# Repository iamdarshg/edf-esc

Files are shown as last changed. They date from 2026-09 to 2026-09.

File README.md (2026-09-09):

# EDF-ESC

Open hardware and firmware for a compact 98 mm × 58 mm, four-layer board with
two independent 6S sensorless BLDC/EDF controller channels.

> **Engineering prototype — do not fabricate or connect a battery.** The CAD
> currently contains documented placement placeholders, open nets, and DRC
> violations. It is not a validated 150 A design. See
> [`docs/cad-status.md`](docs/cad-status.md) for the exact blockers.

## Design targets

- two electrically independent power paths; no shared 300 A PCB segment;
- 18 × SFS06R025GF per channel, three devices per switch;
- DRV8300D gate driver and PY32F030K28U6TR controller per channel;
- high-side copper-shunt/INA190A3 current sensing with four-wire calibration;
- sensorless six-step control with PWM throttle and shared SPI/separate CS;
- shared 12 V gate supply, 5 V/8 A characterization-target BEC, and 3.3 V logic;
- JLCPCB/LCSC-first sourcing with Mouser alternatives and top-side assembly;
- top-side CNC copper reinforcement for every high-current path.

## What works today

The calculation engine, BOM/pin-mux contracts, host protocol, commutation table,
startup/control state machine, zero-cross detector, protection model, and both
channel configuration contracts are covered by native tests. KiCad 7.0.11
parses the generated review CAD and exports plots.

```sh
python3 -m venv .venv
.venv/bin/pip install -e '.[test]'
make test
.venv/bin/python -m edf_esc.cad
```

## Repository map

- `hardware/` — deterministic KiCad review project and design-rule contracts
- `firmware/` — tested portable control core and PY32 pin/configuration contract
- `host/` — SPI framing reference
- `bom/` — primary and alternate sourcing tables
- `calculations/` — gate, MOSFET, shunt, copper, and BEC estimates
- `docs/` — architecture, protocol, safety status, and source ledger

The progression to powered testing is intentionally gated: inspection, gate-only
testing, current-limited low-voltage switching, 3S motor testing, restricted 6S,
then thermal/electrical characterization. A numerical current ceiling is not a
continuous-current rating.

## License

MIT. See [`LICENSE`](LICENSE). Component datasheets and vendor SDK files are not
redistributed unless their licenses permit it.

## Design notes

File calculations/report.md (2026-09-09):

# EDF-ESC preliminary electrical calculations

> Design estimates only. Values that depend on waveforms, copper plating, airflow, component temperature, or undocumented vendor behavior require measurement before power testing.

## Gate drive

Three 81 nC gates place 243 nC on each DRV8300 output. The 0.75 A source and 1.5 A sink ratings give optimistic lower bounds of 324 ns turn-on and 162 ns turn-off. Actual Miller-plateau edges will differ. A 4.7 ohm resistor per MOSFET is the initial damping value; all 36 footprints permit tuning.

At 12 V, gate-charge power per ESC is `18 * 81 nC * 12 V * f`:

| PWM | One ESC | Both ESCs |
|---:|---:|---:|
| 12 kHz | 0.210 W | 0.420 W |
| 16 kHz | 0.280 W | 0.560 W |
| 20 kHz | 0.350 W | 0.700 W |
| 24 kHz | 0.420 W | 0.840 W |

Using the optimistic 486 ns combined edge time, 25.2 V, and 150 A, one hard-switching group dissipates approximately 11.0, 14.7, 18.4, and 22.0 W at 12, 16, 20, and 24 kHz. Modulation can expose more than one group to hard switching, so layout thermal work uses a 1x-2x bracket until double-pulse measurements replace this estimate. This supports the 16 kHz default and argues against 24 kHz during initial tests.

## MOSFET conduction

Assuming 2.0 milliohm per FET at 25 C and a provisional 1.7 hot multiplier, one three-FET group is 1.13 milliohm. A six-step current path contains one high and one low group, or about 2.27 milliohm before copper and sharing error.

| Phase current | Two-group conduction |
|---:|---:|
| 100 A | 22.7 W |
| 120 A | 32.6 W |
| 150 A | 51.0 W |

These are bridge-level path estimates, not per-FET dissipation. Unequal sharing and temperature feedback are validation risks.

## Copper shunt

One 70 um outer-copper strip 11.6 mm long by 28 mm wide calculates to 99.4 microohm at 20 C. At 150 A it produces 14.9 mV and 2.24 W; INA190A3 gain of 100 produces about 1.49 V. At 100 C the copper model rises by about 31%, so four-wire calibration and temperature compensation are mandatory. Finished plating and soldered reinforcement must stop exactly at the Kelvin boundaries.

## 5 V BEC

For 25.2 V to 5.0 V at 180 kHz with 47 uH, ideal duty is 19.84% and calculated inductor ripple is 0.474 A peak-to-peak. At an 8 A target the ideal inductor peak is 8.24 A, so the selected inductor must retain useful inductance comfortably beyond that current. With a provisional 0.55 V diode drop, diode loss alone is about 3.53 W at 8 A. The BEC therefore requires airflow and 2/4/6/8 A thermal characterization; 8 A is not a guaranteed continuous rating.

## BEMF divider and clamp

The starting divider uses two series 47 kOhm upper resistors and 12 kOhm lower,
followed by 1 kOhm into the ADC clamp. At 25.2 V the open divider output is 2.85
V. A deliberately conservative 60 V phase transient would produce 6.79 V if
unclamped. With a 3.6 V clamp model, the upper/lower Thevenin resistance plus the
1 kOhm series resistor limits current to about 0.274 mA. This proves that a naked
divider is unacceptable; it does not close the gate until the exact PY32
injected-current limit, BAT54 leakage, RC settling, and captured phase overshoot
are verified.

## Mandatory measurements

Measure gate plateau/rise/fall, deadtime, phase-node overshoot, bootstrap droop, DC-link ripple, current-sharing proxy temperatures, four-wire shunt resistance, current-amplifier offset/gain, BEMF settling after blanking, and BEC component temperatures. Replace assumptions in `inputs.yaml` only with traceable measurements in `validation/ledger.csv`.

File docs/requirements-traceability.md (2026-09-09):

# Requirements traceability

This table distinguishes implemented evidence from remaining work. “Pass” means
an automated structural or software check passes; it does not imply physical
validation.

| Requirement | Evidence | Status |
|---|---|---|
| One board, two independent ESC paths | `hardware/edf-esc.kicad_pcb`, CAD tests | structural pass |
| ≤100 × 60 mm; four layers; top-side only | 98 × 58 generator contract and tests | pass |
| 36 exact MOSFETs; individual gate resistors | BOM, generated PCB, CAD tests | pass |
| DRV8300D, MCU, INA190 per channel | BOM and review CAD | placement only |
| Proven simultaneous MCU pin mux | `hardware/pinmux.csv`, contract tests | pass |
| BEMF sensing and sensorless control | named CAD nets, `sensorless.c`, tests | firmware pass; analog CAD open |
| PWM throttle + shared SPI/separate CS | pin map, `host/protocol.py`, tests | protocol pass; platform open |
| Command-loss and emergency shutdown | `control.c`, native tests | pass |
| Current, thermal, UV/OV, stall protection | `control.c`, native tests | sampled model pass; hardware open |
| 12 V, 5 V BEC, 3.3 V rails | calculations and BOM | detailed CAD open |
| Loss, shunt, gate, and buck calculations | `calculations/report.md`, calculation tests | pass as estimates |
| Complete connected schematic and exact footprints | `docs/cad-status.md` | blocked |
| Fully routed, zero-error DRC PCB | KiCad DRC report | blocked |
| Target PY32 ELF/HEX/BIN | `docs/firmware.md` | blocked |
| JLCPCB BOM/CPL/Gerbers/drill package | release gate | blocked until CAD passes |
| CNC copper reinforcement drawings | `hardware/mechanical/` | preliminary profiles; final cutouts blocked by routing |
| Physical staged validation at 3S/6S/full load | validation ledger | pending hardware |

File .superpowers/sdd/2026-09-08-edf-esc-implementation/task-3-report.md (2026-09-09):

# Task 3 final report

## Files changed

`edf_esc/cad.py`, `hardware/edf-esc.kicad_sch`, `hardware/lib/edf-esc.kicad_sym`, and structural CAD tests.

## Verification

- `PYTHONPATH=/workspace/scratch/10bf20402490/edf-esc-test-venv-broken/lib/python3.12/site-packages python3 -m pytest tests -q`: 28 passed.
- `make test-c`: all control, sensorless, and platform contract tests passed.
- `python3 -m py_compile edf_esc/cad.py`: passed.
- Generated twice and compared with `cmp`: passed.
- `git diff --check`: passed.
- Exact attachment count: 508 zero-length wires, coincident with serialized pin endpoints.

## KiCad limitation

KiCad CLI bus-errors in this environment; no parse/export success is claimed and ERC was not run.

## Final commit

`112a2f482d7b757c832b0c4c4258686488903111`

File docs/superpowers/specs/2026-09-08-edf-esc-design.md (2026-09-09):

# EDF-ESC Dual 6S Sensorless Controller Design

## Status and safety boundary

EDF-ESC is a public, open engineering prototype for two independently controlled 6S sensorless BLDC/EDF motors. It is not a certified product and is not rated for 150 A continuous operation. Initial firmware restricts current and duty cycle; 150 A is an experimental hard ceiling unlocked only after staged electrical and thermal characterization. Fabrication files remain marked `UNVALIDATED` until the validation ledger records oscilloscope, current-calibration, thermal, and powered-motor results.

## Physical architecture

The board is a 98 mm x 58 mm, four-layer, 1.6 mm FR4 PCB. All components, connectors, test pads, and reinforcement metal are on the top side. ESC A occupies the left power zone and ESC B the right power zone. A central low-current zone contains the shared 12 V gate supply, 5 V BEC, 3.3 V logic rail, and control connector. Each channel has its own battery pads, calibrated shunt geometry, local DC-link capacitors, bridge, phase pads, gate driver, MCU, analog sensing, and return path. The battery is star-split externally; no PCB segment carries both channels' motor current.

Each of the six half-bridge switches per channel contains three SFS06R025GF MOSFETs in parallel. Every MOSFET has its own tunable gate resistor fed by a matched star fan-out from one DRV8300D output. Gate-source pulldowns are per switching group. Optional RC snubbers are fitted across all phase-switching nodes.

## Power path and reinforcement

High-current paths use broad outer-layer polygons, deliberate inner-layer reinforcement, dense via arrays, and short local loops. Top-side solder-mask openings accept CNC-cut 1-2 mm copper bars or braid on BAT+, BAT-, and phase paths. The repository includes dimensioned DXF reinforcement profiles. Eight-AWG cable lands are top-side slotted pads with strain-relief holes. The copper bars are part of the prototype's current path and are not optional at high current.

The layer intent is:

- L1: components, gate fan-outs, local DC-link loops, exposed high-current copper, analog islands.
- L2: channel-local power returns and quiet signal references; split so neither motor return crosses the other channel.
- L3: channel-local battery/phase reinforcement and auxiliary-power distribution.
- L4: additional return/power reinforcement and low-risk signal routing.

No switching node is allowed beneath an MCU, current amplifier, SPI trace, PWM input, or Kelvin pair.

## Sensing and protection

Each BAT+ branch includes a nominal 0.10 milliohm defined copper shunt with true Kelvin boundaries, four-wire calibration pads, and a nearby 10 kohm NTC. An INA190A3 produces the current ADC signal. The PCB also carries an unpopulated metal-shunt fallback footprint. Firmware converts offset-corrected ADC counts through a stored calibration coefficient and optionally compensates copper temperature using 0.0039/K before calibrated corrections.

Each phase has a protected high-impedance BEMF divider, RC filter, ADC series resistor, and clamp chosen so the MCU pin remains inside its injected-current and voltage limits during 6S switching transients. Each channel separately measures VBUS, current, shunt temperature, and power-stage temperature. Floating-phase zero crossing is compared in software with measured VBUS/2.

The hardware break path uses the PY32 comparator-to-TIM1-BREAK route only if the reference manual proves simultaneous pin and internal-route availability. Otherwise, a fast external comparator drives TIM1 BREAK. This independent path is in addition to sampled software current limiting. DRV8300 faults, watchdog, UVLO/OVLO, startup timeout, stall, lost commutation, desynchronization, throttle loss, SPI timeout, and overtemperature all force a coast-safe state.

## Supplies

One XL1509-derived 12 V rail supplies both DRV8300D devices through separate local filters and at least 10 uF local ceramic capacitance per driver. Worst-case average gate-drive demand is calculated from 36 MOSFETs, gate charge, and PWM frequency.

One XL4016E1 non-synchronous buck provides a target 5.0 V/8 A BEC through top-side heavy-wire pads. The design follows the manufacturer's reference topology and documents inductor ripple, saturation current, diode stress, capacitor ripple, and estimated losses. Eight amperes is a characterization target, not a guaranteed continuous rating. An XC6206-class LDO generates 3.3 V for both MCUs and analog circuitry.

## Control and firmware

Each PY32F030K28U6TR uses TIM1 complementary PWM with hardware deadtime. A checked pin-mux table must demonstrate simultaneous six PWM outputs, three BEMF ADC inputs, current ADC, VBUS ADC, at least one NTC ADC, PWM throttle input, SPI slave with independent CS and tri-stated MISO, fault/break, and SWD. If the exact QFN-32 package cannot satisfy this concurrently after all documented remaps, the BOM may move to the cheapest stocked compatible MCU, with the rejected mapping and cost delta recorded.

Both MCUs run the same bare-metal C source with a channel configuration constant. The nonblocking state machine is `DISARMED -> ALIGN -> OPEN_LOOP_RAMP -> CLOSED_LOOP -> FAULT`. Closed-loop six-step commutation blanks switching noise, detects the correct floating-phase crossing around VBUS/2, schedules nominal 30-electrical-degree commutation delay, and applies configurable advance. Default PWM is 16 kHz; supported evaluation settings are 12, 16, 20, and 24 kHz. The default motor is four-pole, while pole count is configurable.

PWM throttle accepts a configurable range centered on 1000-2000 us at 50-400 Hz and becomes invalid after 100 ms. The shared SPI bus uses separate chip selects. Frames contain sync, command, payload length, payload, and CRC-8. Commands cover throttle, arm/disarm, emergency stop, PWM frequency, current limits, ramp rate, optional direction configuration, telemetry, faults, and firmware version. An inactive slave releases MISO.

Default protection starts conservative: a 100 A software target, soft limiting from 120 A, aggressive limiting at 130 A, and an inaccessible 150 A ceiling until characterization data enables it. Temperature warning/derating starts at 80-90 C and shutdown at 100-110 C, all configurable and explicitly described as PCB/NTC rather than junction temperatures.

## Repository deliverables

- `hardware/edf-esc.kicad_sch`, `hardware/edf-esc.kicad_pcb`, project settings, custom symbols, and custom footprints.
- `hardware/mechanical/` with board drawing, STEP export when the CLI supports it, and CNC reinforcement DXF files.
- `firmware/common/`, `firmware/platform/py32f030/`, and channel configurations with reproducible builds.
- `host/` reference SPI encoder/decoder and calibration utilities.
- `tests/` host-executable tests for commutation tables, state transitions, CRC/framing, protection limits, calculations, BOM integrity, pin-mux completeness, and manufacturing-file presence.
- `bom/` with JLCPCB/LCSC-first and Mouser-secondary sourcing, prices captured with dates, alternatives, and selection reasons.
- `calculations/` with machine-readable inputs and generated reports for gates, switching/conduction loss, shunt geometry, BEC, DC-link, and copper loss.
- `manufacturing/` with Gerbers, drill files, BOM/CPL, fabrication notes, assembly drawings, and SHA-256 manifests.

## Verification gates

Automated gates are KiCad ERC with reviewed exclusions, KiCad DRC, board dimension and top-side-only checks, BOM-reference consistency, firmware compilation, host tests, formatting/static analysis, Gerber/drill generation, and clean regeneration from scripts. Passing automation means the files are internally consistent; it does not validate high-current performance.

Physical gates progress through: unpowered inspection; gate-only testing; current-limited low-voltage switching; 3S low-power motor operation; 6S restricted-current operation; then full characterization. Each stage records supply limits, load, waveforms, deadtime, ringing, temperatures, current-calibration error, observed faults, operator, date, and artifact hashes. Full-power use requires validated bus transient margin, equal gate behavior among parallel FETs, stable BEMF handoff, shunt calibration, acceptable MOSFET/PCB/BEC temperatures, and a documented safe operating envelope.

## Engineering assumptions

JLCPCB is the fabrication and primary top-side PCBA target. LCSC is the first sourcing choice and Mouser is the verified secondary source. The board uses separate BAT_A and BAT_B leads from an external star point, 8-AWG cable at full-power experiments, forced airflow from the EDF installation, and soldered top copper reinforcement for any test above the low-current bring-up envelope. Exact component ratings, footprints, availability, and pin functions come from archived manufacturer datasheets, never distributor headlines alone.

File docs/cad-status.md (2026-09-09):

# CAD status

The checked-in CAD is a deterministic **placement and power-topology review
prototype**, not a fabrication release. It is deliberately marked
`UNVALIDATED` on the silkscreen and schematic.

## Verified automatically

- KiCad 7.0.11 parses the board and schematic and exports Gerber/PDF files.
- Outline is 98 mm x 58 mm with four copper layers.
- Every footprint is on the front side.
- There are exactly 36 `SFS06R025GF` positions and 36 individual 4.7 ohm gate
  resistors.
- Channel A and B have independent battery, phase, Kelvin, BEMF, and break nets.
- Source files regenerate byte-for-byte from `python -m edf_esc.cad`.

## Open fabrication blockers

- The centre section now uses package-structured QFN-24, QFN-32-EP, TSOT-23-8,
  SOIC-8, TO-220-5, and SOT-23 pads, but their courtyard, paste, thermal-via,
  assembly, and manufacturer land-pattern dimensions still require final review.
- The schematic is a functional-block review sheet, not the final connected
  electrical schematic.
- The latest local KiCad DRC after assigning the control-device pins reports 895
  violations and 157 unconnected pads. This is expected to rise as real nets
  replace stand-ins; it is not a regression to hide by suppressing checks.
- Copper-zone geometry, gate fan-out, creepage, silkscreen, thermal vias, and
  busbar interfaces need final routing review.
- ERC/DRC must reach reviewed zero-error status before manufacturing files are
  allowed into a release archive.

Do not order this revision. Generated plots are parser smoke-test artifacts only.

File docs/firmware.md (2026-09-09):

# Firmware architecture and status

Both ESCs use the same C11 control sources. `firmware/esc_a/config.h` and
`firmware/esc_b/config.h` change only channel identity; both retain 16 kHz PWM,
a four-pole motor default, and the compile-time high-power lock.

## Implemented and host-tested

- coast-safe six-step output table;
- `DISARMED -> ALIGN -> OPEN_LOOP_RAMP -> CLOSED_LOOP -> FAULT` state machine;
- switching blanking and hysteretic floating-phase zero-cross detection;
- 30-electrical-degree commutation timing with configurable advance;
- current and temperature duty derating;
- latched hard overcurrent, overtemperature, UV, OV, stall, control-timeout,
  and emergency-stop faults;
- CRC-8 command framing and the shared-SPI MISO release rule;
- compile-time validation of the exact QFN-32 TIM1, ADC, throttle, SPI, break,
  and SWD pin allocation for both channel variants.

Run `make test` for the native test suite. The safety core is deliberately free
of PY32 register access so it can be tested with warnings-as-errors and
sanitizers on a workstation.

## Embedded-build blocker

The repository does not yet contain a vendor startup file, CMSIS device header,
linker script, or completed register-level platform implementation. Therefore it
does not yet emit honest `.elf`, `.hex`, or `.bin` images. Those pieces must be
added from a redistributable Puya SDK revision, then the resulting 64 KiB flash / 8
KiB SRAM map must be checked before the firmware is flashed. The pin contract is
ready, but a host build must not be mislabeled as target firmware.

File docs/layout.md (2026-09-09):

# Layout intent and routing constraints

The 98 × 58 mm outline is divided into a left ESC A power cell, a narrow central
control/auxiliary corridor, and a right ESC B power cell. Battery leads star-split
outside the PCB. `BAT_A±` and `BAT_B±` never merge into a board-level motor-current
bus; only low-current auxiliary returns meet at the defined logic star.

Each phase row places three high-side and three low-side PDFN 5×6 devices around a
short local phase polygon. A driver output fans to three equal-length branches,
each terminating in its own 4.7 Ω resistor at the MOSFET gate. Source sense returns
to the driver separately from load copper. Bootstrap capacitor loops must fit
inside the driver/half-bridge cell, with no via in the high-current commutation
loop unless the via array is explicitly modeled.

The current board is not yet routed to this standard. Final routing must enforce:

- 0.5 mm minimum 6S power clearance, increased wherever routing space allows;
- no phase copper below MCU, INA190, SPI, throttle, SWD, or Kelvin routes;
- paired Kelvin traces from the exact copper-shunt boundaries, guarded by quiet
  reference copper and never sharing a current-carrying via;
- high-frequency ceramics directly across each half-bridge local bus loop;
- driver GVDD and bootstrap capacitors adjacent to their pins;
- front-only test points for every gate, phase, bus, current, BEMF, break, and rail;
- at least 1 mm copper-to-edge clearance and isolated M3 keepouts;
- mask openings and mechanical datum holes that register the CNC copper profiles;
- no thermal relief on cable lands or reinforcement interfaces;
- a local via array at each power-pad transition, with drill/aspect ratio accepted
  by the selected JLCPCB four-layer process.

KiCad net classes in `hardware/net-classes.json` are the minimum starting values,
not proof of current capacity. Final current capability depends on the soldered
C110 bars, joints, cable termination, airflow, switching losses, and measured
temperature rise.

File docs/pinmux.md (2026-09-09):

# PY32F030K28U6TR pin-mux decision

The selected QFN-32 K2 device can expose the three complementary TIM1 pairs while retaining six ADC inputs, SPI2, throttle capture, hardware break, reset, and SWD. `hardware/pinmux.csv` is the machine-checked allocation. It is based on PY32F030 Datasheet Rev1.3, QFN32 K2 pin definition table 4-2 and alternate-function tables 4-4/4-5.

TIM1 uses PA8/PA7 for CH1/CH1N, PA9/PB0 for CH2/CH2N, and PA10/PB1 for CH3/CH3N. Analog inputs PA0-PA5 cover current, VBUS, three BEMF phases, and one power-stage NTC. SPI2 avoids those pins by using PF0 SCK, PB7 MOSI, PF1 MISO, and PB8 as software NSS. PB4 captures throttle with TIM3_CH1. PA6 is TIM1_BKIN. PA13/PA14 retain SWD and PF2 retains reset.

## Corrected gate-driver fault requirement

DRV8300DRGER has no `nFAULT` output pin. Its UVLO and cross-conduction features act internally but cannot satisfy the prompt's requested gate-driver-fault input. The design therefore monitors the 12 V gate rail with an external supervisor/comparator on PB5 and routes the fast overcurrent comparator directly to PA6/TIM1_BKIN. Firmware reports `GATE_SUPPLY_FAULT`; it must not mislabel that signal as internal DRV8300 diagnostics.

## ADC-resource consequence

All six conveniently routed ADC channels are used. The base build provides one NTC ADC per channel, satisfying the mandatory requirement. A second NTC footprint can be populated through an analog multiplexer option but is not part of the minimum build because it would add cost and sampling complexity.

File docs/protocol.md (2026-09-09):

# SPI control protocol

Each MCU is an SPI mode-0 slave on the shared clock/MOSI/MISO bus and has an
independent active-low chip select. The inactive slave configures MISO as an
input (high impedance); it must never drive the shared line while its CS is
high.

Frames are `A5 command length payload crc8`. Length is one byte and covers only
the payload. CRC is CRC-8/ATM (polynomial `0x07`, initial value zero) over every
preceding byte including sync. Multi-byte integers are little-endian.

| Value | Command | Request payload |
|---:|---|---|
| `0x01` | ARM | none |
| `0x02` | DISARM | none |
| `0x03` | EMERGENCY_STOP | none; fault latches |
| `0x10` | SET_THROTTLE | duty, `uint16` |
| `0x11` | SET_PWM_FREQUENCY | hertz, `uint32` |
| `0x12` | SET_CURRENT_LIMIT | milliamps, `uint32` |
| `0x13` | SET_RAMP_RATE | electrical steps/s², `uint32` |
| `0x14` | SET_DIRECTION | `0` forward, `1` reverse |
| `0x20` | READ_TELEMETRY | none |
| `0x21` | READ_FAULTS | none |
| `0x22` | READ_VERSION | none |

Any malformed length, unknown command, or CRC mismatch is discarded without
changing outputs. The valid-control watchdog is refreshed only after a complete,
accepted control frame. It forces a latched coast-safe fault after 100 ms.

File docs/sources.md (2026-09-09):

# Controlled engineering sources

Only manufacturer documents can close an electrical or pin-mux gate. Distributor pages support stock, price, and ordering identity but not design limits.

| Component | Controlled source | Facts used | Status |
|---|---|---|---|
| TI DRV8300 | https://www.ti.com/lit/ds/symlink/drv8300.pdf, Rev. D (March 2022), SHA-256 `bb467652a531335d23ea67644db1db26ce53f149e3f889f8158a1c3ddac3e4db` | 5-20 V GVDD, 750 mA source, 1.5 A sink, QFN variable deadtime, integrated bootstrap diode on D variant, pinout/layout | verified from manufacturer PDF |
| TI INA190 | https://www.ti.com/lit/ds/symlink/ina190.pdf, Rev. D, SHA-256 `6ed9c2cc41d6c5ba4f36ce33d9d829b2f0c51e376583e94e2c63be4d950b39af` | common-mode range, gain option, supply/ADC interface, layout | verified from manufacturer PDF |
| PUYA PY32F030 | LCSC manufacturer PDF mirror, Datasheet Rev1.3, SHA-256 `38262b8a2c8320567f7f80594d4e9558cd0721edacbe360e37839284c0d04a4f` | exact QFN-32 K2 pins, alternate functions and ADC channels | pin map verified; comparator internal routing still requires reference-manual evidence |
| Oriental Semiconductor SFS06R025GF | Manufacturer PDF V1.0, SHA-256 `6a947af2537023168338109af4bddd3e03c0364027fd04a3ce05bfe177fd5f03` | 60 V, 2.5 mOhm maximum at 10 V, 81 nC Qg, 16 nC Qgd, PDFN 5x6 pinout | verified from manufacturer PDF; thermal assumptions remain a physical validation gate |
| XLSEMI XL4016E1 | Manufacturer datasheet, 8 A/180 kHz/40 V family | reference circuit, feedback, inductor, diode, capacitors, thermal limits | secondary mirror located; manufacturer PDF must be archived |
| XLSEMI/UMW XL1509 | Manufacturer datasheet for exact ordered variant | 12 V buck reference circuit and magnetics | validation gate before schematic release |
| XC6206P332MR | Torex manufacturer datasheet | pinout, 3.3 V regulation, capacitor stability, current/thermal limits | validation gate before schematic release |

## Distributor capture

LCSC product pages were captured on 2026-09-09 for ordering identity, prototype
price, and stock only: C49005839 (259), C3655801 (11,428), C3018718 (18,245),
C1852076 (8,100), C55881 (26,710), and C2681227 (13,060). Distributor values do
not override the electrical limits above. Prices in `bom/edf-esc.csv` use the
lowest applicable quantity tier for one board, including LCSC minimum-order
tiers where relevant.

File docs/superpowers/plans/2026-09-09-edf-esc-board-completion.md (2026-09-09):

# EDF-ESC Board Completion Implementation Plan

> **For agentic workers:** REQUIRED SUB-SKILL: Use superpowers:subagent-driven-development (recommended) or superpowers:executing-plans to implement this plan task-by-task. Steps use checkbox (`- [ ]`) syntax for tracking.

**Goal:** Turn the existing EDF-ESC engineering prototype into a complete, pin-accurate, ERC/DRC-clean dual-6S KiCad design with target firmware and reproducible JLCPCB manufacturing outputs, while keeping the public repository honest about unvalidated high-current performance.

**Architecture:** Keep the 98 mm × 58 mm mirrored board: ESC A on the left, ESC B on the right, and low-current auxiliary/control circuitry in the centre. Make a connected KiCad schematic the sole netlist authority, then update the PCB from it; use channel-local high-current loops and top-side CNC copper reinforcement so no PCB segment carries combined motor current. Continue the deterministic Python generators, fail-closed release gate, and shared host-tested firmware core with channel-specific PY32 configuration.

**Tech Stack:** KiCad 9 source format with KiCad 7.0.11 compatibility checks, Python 3.12/pytest, C11, GNU Arm Embedded, JLCPCB/LCSC assembly conventions, Mouser secondary sourcing, Git/GitHub Actions.

**Spec:** `docs/superpowers/specs/2026-09-08-edf-esc-design.md`

## Global Constraints

- Board outline remains exactly 98 mm × 58 mm and never exceeds 100 mm × 60 mm.
- Four copper layers, 1.6 mm FR4; 2 oz all layers where economical, otherwise 2 oz outer layers and the thickest economical inner copper with the deviation documented.
- All component bodies, connectors, cable lands, test pads, and reinforcement remain top-side only.
- BAT_A and BAT_B remain independent from their external star split through their local bridges; no combined-current PCB net or segment is allowed.
- Exactly 36 SFS06R025GF MOSFETs: three per switch, 18 per ESC, with one tunable gate resistor per MOSFET and no daisy-chained gates.
- One DRV8300DRGER and one PY32F030K28U6TR per ESC; do not invent a DRV8300 `nFAULT` pin.
- Default PWM remains 16 kHz; firmware retains 12/16/20/24 kHz evaluation options.
- Default limits remain 100 A target, 120 A soft limit, 130 A aggressive limit, and a locked 150 A experimental ceiling.
- JLCPCB/LCSC is the primary build path; Mouser is the verified secondary source.
- Automation proves internal consistency only. The project remains `UNVALIDATED` and non-fabrication-ready until ERC, DRC, sourcing, and staged physical gates are complete.

---

### Task 1: Publish and continuously synchronize the engineering baseline

**Files:**
- Modify: Git remote `iamdarshg/EDF-ESC`, branch `main`
- Verify: `.github/workflows/ci.yml`, `README.md`, `docs/cad-status.md`

**Interfaces:**
- Consumes: local audited commits and GitHub public repository created by the user.
- Produces: a public source-of-truth branch whose visible head is recorded after every reviewed milestone.

- [ ] Create one Git tree containing every `git ls-files` path, preserving mode `100644`/`100755`.
- [ ] Commit that tree on remote `main` with the existing seed commit as parent.
- [ ] Fetch the remote head and compare the uploaded file set and representative SHA/content for `hardware/edf-esc.kicad_pcb`, `edf_esc/cad.py`, and `scripts/check_release.py`.
- [ ] Keep `README.md` and `docs/cad-status.md` explicit that the current CAD is not safe to fabricate.
- [ ] After every later task passes review, publish its commit and re-verify the remote head.

Verification:

```sh
git ls-files | sort
git status --short
git diff --check
```

Commit message: `chore: publish EDF-ESC engineering baseline`

### Task 2: Freeze pin-accurate symbols and manufacturer land patterns

**Files:**
- Modify: `edf_esc/cad.py`
- Modify: `hardware/lib/edf-esc.kicad_sym`
- Modify: `hardware/lib/edf-esc.pretty/*.kicad_mod`
- Create: `tests/test_kicad_structure.py`
- Create: `docs/footprint-review.md`

**Interfaces:**
- Consumes: archived manufacturer drawings and the frozen MCU pin-mux table.
- Produces: `SYMBOL_PIN_MAPS`, `FOOTPRINT_SPECS`, deterministic symbol/footprint files, and an evidence row for every custom package.

- [ ] Add failing tests that assert DRV8300 RGE pins 1–25, PY32 QFN32 pins 1–33, INA190 DDF pins 1–8, and SFS06R025GF source/gate/drain pad mapping.
- [ ] Run the focused tests and confirm they fail because current symbols use anonymous `P1...Pn` names and provisional geometry.
- [ ] Implement named electrical pin maps and assign the exact custom footprint in every symbol's `Footprint` property.
- [ ] Replace provisional QFN/PDFN/TSOT/SOIC/SOT/TO-220 dimensions with values transcribed from manufacturer drawings; add pin-1, fab, silk, courtyard, paste, exposed-pad, and thermal-via details where required.
- [ ] Record datasheet page/revision, dimension, tolerance, and verification status in `docs/footprint-review.md`; mark unresolved geometry as a fabrication blocker.
- [ ] Regenerate twice and byte-compare the outputs.

Verification:

```sh
python -m pytest tests/test_kicad_structure.py -v
python -m edf_esc.cad
git diff --check
```

Commit message: `feat: verify EDF-ESC symbols and land patterns`

### Task 3: Build the complete connected dual-channel schematic

**Files:**
- Modify: `edf_esc/cad.py`
- Modify: `hardware/edf-esc.kicad_sch`
- Modify: `tests/test_kicad_structure.py`
- Create: `docs/erc-review.md`

**Interfaces:**
- Consumes: Task 2 symbols/footprints, BOM identities, and `hardware/pinmux.csv`.
- Produces: an annotated electrical netlist for power input, ESC A, ESC B, sensing/protection, auxiliary rails, and control/debug.

- [ ] Add failing structural tests for 36 FET symbols, 36 gate resistors, 12 group pulldowns, six bootstrap capacitors, six BEMF dividers/filters, two VBUS dividers, two INA190 channels, two external hardware-break paths, local DC-link capacitors, SWD, PWM throttle, and shared SPI with separate CS.
- [ ] Add failing assertions for independent `BAT_A±`/`BAT_B±`, Kelvin boundaries, and the absence of `BAT_COMBINED` and fabricated driver-fault nets.
- [ ] Generate real symbol instances, numbered pins, wires, junctions, labels, values, references, and assigned footprints; use hierarchical sheets or clearly separated functional sections.
- [ ] Connect each DRV8300 to matched star gate-resistor fan-outs, bootstrap networks, local GVDD filtering, its MCU PWM pins, and its local three-phase bridge.
- [ ] Connect current, VBUS, BEMF, NTC, comparator/BKIN, throttle, SPI, SWD, reset, and auxiliary supply circuits with explicit values from calculation inputs/BOM.
- [ ] Run ERC, resolve genuine faults, and document each intentional exclusion with its exact reference/pin and rationale.

Verification:

```sh
python -m pytest tests/test_kicad_structure.py -v
kicad-cli sch erc -o build/erc.rpt hardware/edf-esc.kicad_sch
rg '^(ERROR|WARNING)' build/erc.rpt
```

Acceptance: parser-valid schematic, zero unexplained ERC errors, exact component counts, and deterministic regeneration.

Commit message: `feat: add connected dual ESC schematic`

### Task 4: Re-place the board around real switching and sensing loops

**Files:**
- Modify: `edf_esc/cad.py`
- Modify: `hardware/edf-esc.kicad_pcb`
- Create: `tests/test_pcb_policy.py`
- Modify: `docs/layout.md`

**Interfaces:**
- Consumes: Task 3 netlist and Task 2 land patterns.
- Produces: locked placement, board stack-up, keepouts, net classes, and measurable routing constraints.

- [ ] Add failing tests for driver-to-gate-resistor distance, matched three-way fan-out length, bootstrap adjacency, local DC-link loop location, Kelvin separation, switching-node keepouts, board edge clearance, top-side-only placement, and reinforcement keepouts.
- [ ] Update the PCB from the schematic without deleting valid reference identities or channel-specific nets.
- [ ] Place each DRV8300 inside its six-switch bank; put each bootstrap capacitor at its driver pins and each gate resistor at its MOSFET gate branch.
- [ ] Place local bulk/ceramic DC-link capacitors directly across each channel's bridge supply loop and keep phase copper away from MCUs, ADC nets, SPI, throttle, SWD, and Kelvin pairs.
- [ ] Lock the accepted placement and record all measurable constraints in `docs/layout.md` and `hardware/net-classes.json`.

Verification:

```sh
python -m pytest tests/test_pcb_policy.py -v
kicad-cli pcb render -o build/board.png hardware/edf-esc.kicad_pcb
git diff --check
```

Commit message: `feat: place EDF-ESC around local power loops`

### Task 5: Route the four-layer PCB and CNC reinforcement system

**Files:**
- Modify: `edf_esc/cad.py`
- Modify: `hardware/edf-esc.kicad_pcb`
- Modify: `hardware/mechanical/reinforcement.csv`
- Modify: `hardware/mechanical/reinforcement.dxf`
- Modify: `tests/test_pcb_policy.py`
- Modify: `docs/layout.md`

**Interfaces:**
- Consumes: locked placement/net classes.
- Produces: fully routed copper, zones, via arrays, exposed reinforcement lands, and dimensioned CNC profiles.

- [ ] Route gate drives first as short, non-daisy-chained matched stars with clean source returns.
- [ ] Route Kelvin/current/BEMF/NTC/MCU/SPI/SWD signals with channel-local quiet reference and no switching copper beneath them.
- [ ] Route BAT+, BAT−, and U/V/W as channel-local polygon systems across appropriate layers with dense current-sharing/thermal vias and no combined-current neck.
- [ ] Add solder-mask openings and mechanical keepouts for 1–2 mm top copper reinforcement; revise DXF/CSV to match the final copper coordinates and mounting clearance.
- [ ] Fill zones, run DRC, fix every error, and document only demonstrably safe waivers.
- [ ] Render and inspect all copper layers, solder mask, courtyard, edge cuts, and reinforcement overlays.

Verification:

```sh
kicad-cli pcb drc --exit-code-violations -o build/drc.rpt hardware/edf-esc.kicad_pcb
kicad-cli pcb gerbers -o build/gerbers hardware/edf-esc.kicad_pcb
python -m pytest tests/test_pcb_policy.py tests/test_mechanical.py -v
```

Acceptance: zero unreviewed DRC violations, zero unconnected pads, exact 98 × 58 mm outline, top-only assembly, and CNC profiles aligned with final board copper.

Commit message: `feat: route four-layer EDF-ESC power board`

### Task 6: Complete and build the PY32F030 target firmware

**Files:**
- Create: `firmware/platform/py32f030/startup.c`
- Create: `firmware/platform/py32f030/platform.c`
- Create: `firmware/platform/py32f030/registers.h`
- Create: `firmware/CMakeLists.txt`
- Create: `firmware/toolchain-arm-none-eabi.cmake`
- Modify: `firmware/esc_a/config.h`, `firmware/esc_b/config.h`
- Modify: `docs/firmware.md`
- Create: `docs/flash-and-debug.md`

**Interfaces:**
- Consumes: tested `firmware/common` APIs and frozen pinmux.
- Produces: ESC A/B ELF, HEX, BIN and map files with identical logic and channel-specific configuration.

- [ ] Add a failing compile/link target for every `platform.h` function and static assertions for timer/ADC/SPI/SWD pin assignments.
- [ ] Implement reset, clock, safe GPIO startup, TIM1 complementary PWM/deadtime/BKIN, triggered ADC, comparator/external-break input, throttle capture, SPI slave/MISO release, watchdog, and fault ISR without blocking delays.
- [ ] Keep outputs disabled until initialization, valid arm sequence, and protection checks complete.
- [ ] Build both channel variants with warnings as errors; inspect maps against 64 KB flash and 8 KB SRAM.
- [ ] Run all host tests and record toolchain/version/hash in `docs/firmware.md`.

Verification:

```sh
cmake -S firmware -B build/firmware -DCMAKE_TOOLCHAIN_FILE=firmware/toolchain-arm-none-eabi.cmake
cmake --build build/firmware -- -j2
ctest --test-dir build/firmware --output-on-failure
make test-c
```

Commit message: `feat: add buildable PY32F030 ESC firmware`

### Task 7: Lock JLCPCB/LCSC and Mouser manufacturing data

**Files:**
- Modify: `bom/edf-esc.csv`, `bom/alternates.csv`, `bom/cost-summary.md`
- Create: `manufacturing/edf-esc-bom.csv`, `manufacturing/edf-esc-cpl.csv`
- Create: `docs/sourcing-review.md`
- Modify: `validation/ledger.csv`

**Interfaces:**
- Consumes: final references, footprints, rotation/origin data, and selected MPNs.
- Produces: JLCPCB-ready BOM/CPL plus source/date/stock/price evidence and Mouser fallbacks.

- [ ] Validate every primary LCSC code against exact MPN, package, lifecycle, stock, assembly class, and captured unit price/date.
- [ ] Validate at least one electrically/package-compatible Mouser alternative for each critical IC, MOSFET class, diode, inductor, capacitor bank, connector, and protection component.
- [ ] Generate BOM/CPL from the final board; assert exact reference-set equality, top-side-only placement, legal rotations, and no missing required MPN/LCSC fields.
- [ ] Separate hand-installed busbars, 8-AWG leads, and other non-PCBA items from JLC placement rows.
- [ ] Recompute prototype cost with priced and unpriced totals stated separately.

Verification:

```sh
python -m pytest tests/test_contracts.py tests/test_bom_cost.py -v
python scripts/check_release.py
```

Commit message: `build: lock JLCPCB and Mouser sourcing data`

### Task 8: Generate release outputs and perform the final fail-closed audit

**Files:**
- Modify: `scripts/release.sh`, `scripts/check_release.py`
- Populate: `manufacturing/gerbers/`, `manufacturing/drill/`
- Create: `manufacturing/SHA256SUMS`, fabrication/assembly drawings, schematic PDF, STEP export when supported
- Modify: `docs/bring-up.md`, `docs/calibration.md`, `docs/thermal-characterization.md`, `docs/cad-status.md`, `README.md`, `CHANGELOG.md`

**Interfaces:**
- Consumes: Tasks 3–7 outputs.
- Produces: reproducible manufacturing archive and an explicit staged-validation envelope.

- [ ] Run full Python/C/firmware/ERC/DRC checks from a clean build directory.
- [ ] Generate Gerbers, drills, BOM, CPL, schematic PDF, layer/fabrication drawings, and STEP; reject empty or stale outputs.
- [ ] Generate twice and compare SHA-256 manifests for deterministic source-derived files.
- [ ] Audit every original requirement against `docs/requirements-traceability.md` and fail on uncovered mandatory rows.
- [ ] Keep fabrication blocked until sourcing fields are verified and ERC/DRC are clean; keep full-power status blocked until staged physical evidence exists.
- [ ] Publish the reviewed source commit. Publish manufacturing artifacts only if their embedded validation status matches the repository.

Verification:

```sh
python -m pytest tests -v
make test-c
kicad-cli sch erc --exit-code-violations -o build/erc.rpt hardware/edf-esc.kicad_sch
kicad-cli pcb drc --exit-code-violations -o build/drc.rpt hardware/edf-esc.kicad_pcb
scripts/release.sh
python scripts/check_release.py
git diff --check
git status --short
```

Commit message: `release: add unvalidated EDF-ESC fabrication candidate`

## Execution policy

- Use Luna for focused implementation and mechanical review tasks by default.
- Use one implementation subagent at a time in the shared worktree; run independent read-only sourcing/layout audits in parallel when capacity permits.
- Every task follows red → green → refactor, then a separate spec/quality review before publication.
- Never suppress ERC/DRC errors merely to make the count reach zero.
- Never publish or label a fabrication release without the explicit fail-closed gates above.

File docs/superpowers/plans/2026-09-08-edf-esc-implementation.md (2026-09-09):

# EDF-ESC Implementation Plan

> **For agentic workers:** REQUIRED SUB-SKILL: Use superpowers:subagent-driven-development (recommended) or superpowers:executing-plans to implement this plan task-by-task. Steps use checkbox (`- [ ]`) syntax for tracking.

**Goal:** Produce a reproducible, reviewable KiCad 9 dual-ESC prototype, bare-metal PY32 firmware, sourcing package, calculations, manufacturing outputs, and staged bring-up documentation.

**Architecture:** A mirrored 98 x 58 mm four-layer board keeps each 150 A-class branch local and independent while sharing only auxiliary supplies and logic ground. Host-testable motor-control/protocol code is separated from PY32 register access, and deterministic generators/checkers make electrical calculations and release artifacts auditable.

**Tech Stack:** KiCad 9 and `kicad-cli`, C11/CMake, Python 3.12/pytest, JLCPCB Gerber/CPL/BOM conventions, GNU Arm Embedded toolchain where available.

**Spec:** `docs/superpowers/specs/2026-09-08-edf-esc-design.md`

## Global Constraints

- PCB outline is 98 mm x 58 mm and never exceeds 100 mm x 60 mm.
- Four copper layers; all bodies, connectors, pads, and reinforcement are top-side only.
- Two independent 6S power paths; no common PCB segment carries combined motor current.
- Exactly 36 SFS06R025GF MOSFETs, three per switch, with one resistor per gate.
- Default firmware PWM is 16 kHz and full-power operation is locked behind characterization.
- JLCPCB/LCSC is primary; Mouser is the verified secondary source.
- Automated checks do not constitute a validated 150 A continuous rating.

---

### Task 1: Reproducible engineering calculations and source ledger

**Files:**
- Create: `pyproject.toml`, `edf_esc/__init__.py`, `edf_esc/calculations.py`, `tests/test_calculations.py`
- Create: `calculations/inputs.yaml`, `calculations/report.md`, `docs/sources.md`

**Interfaces:**
- Produces: `gate_metrics(qg_c, count, source_a, sink_a, frequency_hz)`, `fet_losses(current_a, rds_hot_ohm, voltage_v, tr_s, tf_s, frequency_hz)`, `copper_resistance(length_m, width_m, thickness_m, layers)`, and `buck_ripple(vin_v, vout_v, current_a, frequency_hz, inductance_h)`.

- [ ] Write tests asserting 243 nC group charge, current-limited edge times, positive loss scaling, 0.10 milliohm shunt geometry tolerance, and buck inductor ripple.
- [ ] Run `python -m pytest tests/test_calculations.py -v` and confirm missing-module failure.
- [ ] Implement dimensionally explicit calculations and YAML-to-Markdown report generation.
- [ ] Run the test again and confirm all assertions pass.
- [ ] Record manufacturer document URL, revision/date, SHA-256 when archived, and which design fact each source supports.
- [ ] Commit with `git commit -m "feat: add reproducible electrical calculations"`.

### Task 2: BOM, pin mux, and design-rule contracts

**Files:**
- Create: `bom/edf-esc.csv`, `bom/alternates.csv`, `hardware/pinmux.csv`, `hardware/net-classes.json`
- Create: `edf_esc/contracts.py`, `tests/test_contracts.py`

**Interfaces:**
- Produces: parsers that validate reference counts, mandatory columns, exact part identities, six complementary PWM signals, analog channels, SPI/SWD/fault coexistence, and top-side-only placement policy.

- [ ] Write failing tests for 36 MOSFETs, two drivers/MCUs/current amplifiers, mandatory distributor fields, duplicate MCU pins, missing functions, and forbidden back-side footprints.
- [ ] Run `python -m pytest tests/test_contracts.py -v` and verify the fixtures fail for missing implementation.
- [ ] Implement CSV/JSON validators and populate the pin-mux evidence table from the exact QFN-32 datasheet/reference manual.
- [ ] Populate priced sourcing rows with capture dates; mark unavailable facts as `validation_required` rather than inventing them.
- [ ] Re-run contract tests and commit with `git commit -m "feat: freeze BOM and pin-mux contracts"`.

### Task 3: KiCad library and schematic

**Files:**
- Create: `hardware/edf-esc.kicad_pro`, `hardware/edf-esc.kicad_sch`
- Create: `hardware/lib/edf-esc.kicad_sym`, `hardware/lib/edf-esc.pretty/*.kicad_mod`
- Create: `hardware/sym-lib-table`, `hardware/fp-lib-table`, `tests/test_kicad_structure.py`

**Interfaces:**
- Consumes: BOM identities and verified pin mapping.
- Produces: annotated hierarchical schematic sheets for power input, ESC A, ESC B, auxiliary rails, and control/debug.

- [ ] Write structural tests that reject absent sheets, missing gate resistors, incorrect MOSFET count, missing Kelvin/calibration nodes, missing BEMF channels, and unconnected safety nets.
- [ ] Run `python -m pytest tests/test_kicad_structure.py -v` and confirm failure because the schematic does not exist.
- [ ] Create verified symbols/footprints from mechanical drawings, including exposed pads and courtyard/paste rules.
- [ ] Create the complete hierarchical schematic, annotate it, and assign footprints.
- [ ] Run structural tests and `kicad-cli sch erc -o build/erc.rpt hardware/edf-esc.kicad_sch`; review every exclusion in `docs/erc-review.md`.
- [ ] Commit with `git commit -m "feat: add complete dual ESC schematic"`.

### Task 4: Four-layer PCB and mechanical reinforcement

**Files:**
- Create: `hardware/edf-esc.kicad_pcb`, `hardware/mechanical/*.dxf`, `hardware/mechanical/reinforcement.csv`
- Create: `tests/test_pcb_policy.py`, `docs/layout.md`

**Interfaces:**
- Produces: a routed board with mirrored local power loops, explicit layer stack, net classes, via arrays, exposed copper zones, and CNC copper profiles.

- [ ] Write failing checks for board bounds, four layers, no bottom-side items, no shared combined-current net, driver-to-gate geometry, local bulk capacitors, top test pads, edge clearance, and reinforcement-profile dimensions.
- [ ] Run the policy test and confirm it fails because the board is absent.
- [ ] Place and route ESC A, mirror electrical intent for ESC B without copying net identities, then place central auxiliary supplies and controls.
- [ ] Add zones, thermal-via arrays, solder-mask openings, keepouts, silkscreen safety labels, mounting holes, and top reinforcement features.
- [ ] Run `kicad-cli pcb drc -o build/drc.rpt hardware/edf-esc.kicad_pcb`, inspect 3D clearance, and resolve all non-waived violations.
- [ ] Commit with `git commit -m "feat: route four-layer dual ESC board"`.

### Task 5: Host-tested control core and SPI protocol

**Files:**
- Create: `firmware/common/*.c`, `firmware/include/edf_esc/*.h`, `firmware/tests/*.c`, `firmware/CMakeLists.txt`
- Create: `host/protocol.py`, `tests/test_protocol.py`, `docs/protocol.md`

**Interfaces:**
- Produces: `esc_step()`, `commutation_apply_sector()`, `protection_evaluate()`, `crc8()`, frame encode/decode, telemetry schema, and deterministic state transitions.

- [ ] Write failing C tests for six valid sectors, safe invalid-sector output, alignment/ramp/handoff, 100 ms control loss, overcurrent tiers, overtemperature, UV/OV, stall/desync, and emergency stop.
- [ ] Write failing Python tests for sync, payload length, CRC rejection, command round trips, and MISO-release semantics.
- [ ] Run `ctest --test-dir build/firmware --output-on-failure` and `python -m pytest tests/test_protocol.py -v`; confirm expected failures.
- [ ] Implement the smallest nonblocking control core and binary protocol that passes each test.
- [ ] Re-run both suites, use sanitizers for the host C build, and commit with `git commit -m "feat: implement tested ESC control core"`.

### Task 6: PY32F030 platform firmware

**Files:**
- Create: `firmware/platform/py32f030/*.c`, `firmware/platform/py32f030/*.h`, `firmware/esc_a/config.h`, `firmware/esc_b/config.h`, `firmware/toolchain-arm-none-eabi.cmake`
- Create: `docs/firmware.md`, `docs/flash-and-debug.md`

**Interfaces:**
- Consumes: common control core and frozen pin map.
- Produces: TIM1 complementary PWM/deadtime/break, timer-triggered ADC sampling, throttle capture, SPI slave, watchdog, and SWD firmware images.

- [ ] Add compile-time assertions tying peripheral pins/channels to the pin-mux contract and tests that both channel configs retain conservative limits.
- [ ] Confirm the target build fails before platform functions are defined.
- [ ] Implement reset/startup, clocks, GPIO safe state, TIM1, ADC, comparators/break, input capture, SPI, watchdog, and fault ISR without blocking motor-control delays.
- [ ] Build both variants with warnings as errors, inspect map files for 64 KB flash/8 KB SRAM limits, and generate `.elf`, `.hex`, and `.bin` artifacts.
- [ ] Commit with `git commit -m "feat: add PY32 dual-channel firmware targets"`.

### Task 7: Manufacturing, calibration, and bring-up package

**Files:**
- Create: `scripts/release.sh`, `scripts/check_release.py`, `manufacturing/README.md`
- Create: `docs/bring-up.md`, `docs/calibration.md`, `docs/thermal-characterization.md`, `validation/ledger.csv`
- Generate: `manufacturing/gerbers/*`, `manufacturing/drill/*`, `manufacturing/edf-esc-bom.csv`, `manufacturing/edf-esc-cpl.csv`, `manufacturing/SHA256SUMS`

**Interfaces:**
- Produces: one-command deterministic release package and staged test forms for modes 1-5.

- [ ] Write failing release checks for required files, nonempty plots, matching references, board dimensions, top-side CPL entries, and hash-manifest integrity.
- [ ] Generate Gerbers, drills, position files, BOM, schematic PDF, assembly/fabrication drawings, and STEP model using `kicad-cli`.
- [ ] Document four-wire shunt calibration, BEMF observation, deadtime/ringing capture, BEC loads at 2/4/6/8 A, and abort criteria.
- [ ] Run release checks from a clean build directory twice and compare hashes for deterministic source-derived outputs.
- [ ] Commit with `git commit -m "build: add manufacturing and bring-up package"`.

### Task 8: Final audit and public release

**Files:**
- Create: `README.md`, `LICENSE`, `.github/workflows/ci.yml`, `CHANGELOG.md`
- Modify: validation/status badges only from actual command results.

**Interfaces:**
- Produces: public repository with reproducible CI and explicit prototype status.

- [ ] Map every source-prompt requirement to a file/test in `docs/requirements-traceability.md` and fail CI for uncovered mandatory rows.
- [ ] Run full pytest, host C tests/sanitizers, both embedded builds, ERC, DRC, release generation, archive inspection, and `git diff --check`.
- [ ] Confirm README never claims validated current or BEC performance and gives staged safety instructions before file links.
- [ ] Create the public `iamdarshg/EDF-ESC` repository, push `main`, and verify the remote commit equals the locally audited commit.
- [ ] Publish release artifacts only when the validation status inside them matches the repository status.

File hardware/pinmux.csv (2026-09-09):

function | pin | peripheral | af | mode | evidence
PWM_U_H | PA8 | TIM1_CH1 | AF2 | alternate push-pull | PY32F030 Rev1.3 tables 4-2 and 4-4
PWM_U_L | PA7 | TIM1_CH1N | AF2 | alternate push-pull | PY32F030 Rev1.3 tables 4-2 and 4-4
PWM_V_H | PA9 | TIM1_CH2 | AF2 | alternate push-pull | PY32F030 Rev1.3 tables 4-2 and 4-4
PWM_V_L | PB0 | TIM1_CH2N | AF2 | alternate push-pull | PY32F030 Rev1.3 tables 4-2 and 4-5
PWM_W_H | PA10 | TIM1_CH3 | AF2 | alternate push-pull | PY32F030 Rev1.3 tables 4-2 and 4-4
PWM_W_L | PB1 | TIM1_CH3N | AF2 | alternate push-pull | PY32F030 Rev1.3 tables 4-2 and 4-5
BEMF_U | PA2 | ADC_IN2 | analog | analog input | PY32F030 Rev1.3 table 4-2
BEMF_V | PA3 | ADC_IN3 | analog | analog input | PY32F030 Rev1.3 table 4-2
BEMF_W | PA4 | ADC_IN4 | analog | analog input | PY32F030 Rev1.3 table 4-2
CURRENT | PA0 | ADC_IN0 | analog | analog input | PY32F030 Rev1.3 table 4-2
VBUS | PA1 | ADC_IN1 | analog | analog input | PY32F030 Rev1.3 table 4-2
NTC_POWER | PA5 | ADC_IN5 | analog | analog input | PY32F030 Rev1.3 table 4-2
THROTTLE_PWM | PB4 | TIM3_CH1 | AF1 | input capture | PY32F030 Rev1.3 tables 4-2 and 4-5
SPI_SCLK | PF0 | SPI2_SCK | AF0 | alternate input | PY32F030 Rev1.3 tables 4-2 and 4-4
SPI_MOSI | PB7 | SPI2_MOSI | AF1 | alternate input | PY32F030 Rev1.3 tables 4-2 and 4-5
SPI_MISO | PF1 | SPI2_MISO | AF0 | alternate push-pull tristated | PY32F030 Rev1.3 tables 4-2 and 4-4
SPI_CS | PB8 | GPIO |  | input pull-up | PY32F030 Rev1.3 table 4-2 QFN32 K2
BREAK | PA6 | TIM1_BKIN | AF2 | alternate input | PY32F030 Rev1.3 tables 4-2 and 4-4
GATE_SUPPLY_FAULT | PB5 | GPIO |  | input pull-up | External 12 V supervisor because DRV8300 has no nFAULT pin
SWDIO | PA13 | SWDIO | AF0 | debug | PY32F030 Rev1.3 tables 4-2 and 4-4
SWCLK | PA14 | SWCLK | AF0 | debug | PY32F030 Rev1.3 tables 4-2 and 4-4
NRST | PF2 | NRST |  | reset | PY32F030 Rev1.3 table 4-2

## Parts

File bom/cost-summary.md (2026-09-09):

# BOM cost status

Priced significant-component subtotal: **$27.39** across 6 rows.

Unpriced rows: **33**. These are not counted as zero; therefore no final assembled-board cost is claimed. Pricing uses consumed quantity rather than full reel/tube purchase cost and excludes PCB, assembly, shipping, tax, CNC copper, wire, and rework.

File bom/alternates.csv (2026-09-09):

function | primary | alternate | reason | status
power_mosfet | SFS06R025GF | none approved | Package and switching equivalence must be reviewed before substitution | locked
gate_driver | DRV8300DRGER | Mouser 595-DRV8300DRGER | Exact MPN secondary distributor; D variant and QFN variable deadtime are required | price_and_stock_review_required
current_amplifier | INA190A3IDDFR | Mouser 595-INA190A3IDDFR | Exact MPN secondary distributor and exact pinout | price_and_stock_review_required
current_amplifier_cost_down | INA190A3IDDFR | INA186A3IDDFR | Same nominal gain and LCSC-listed pin-compatible alternative; common-mode transient and accuracy review required | electrical_review_required
logic_mcu | PY32F030K28U6TR | none approved | Pin map is specific to QFN32 K2 | locked
bec_buck | XL4016E1 | SMD 36 V 8 A buck | Only if through-hole assembly or thermal testing rejects XL4016 | cost_review_required
bulk_capacitor | EEU-FS1V471 | Mouser 667-EEU-FS1V471 | Exact Panasonic MPN secondary source | fit_stock_and_ripple_review_required
gate_resistor | RC0603FR-074R7L | Mouser 603-RC0603FR-074R7L | Exact Yageo MPN secondary source | verified_family
temperature_sensor | NCP21XH103J03RA | Mouser 81-NCP21XH103J03RA | Exact Murata MPN secondary source | verified_family

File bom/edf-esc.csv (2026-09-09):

reference | quantity | manufacturer | mpn | distributor | distributor_part_number | unit_price_usd | extended_price_usd | price_captured | alternate_part | reason_selected | status
QA1-QA18 QB1-QB18 | 36 | Oriental Semiconductor | SFS06R025GF | LCSC | C49005839 | 0.5670 | 20.4120 | 2026-09-09 |  | Required 60 V 2.5 mOhm max at 10 V and 81 nC MOSFET; 259 stocked; 30+ price | datasheet_and_stock_verified
UGA UGB | 2 | Texas Instruments | DRV8300DRGER | LCSC | C3655801 | 0.6152 | 1.2304 | 2026-09-09 |  | 100 V three-phase driver with integrated bootstrap diodes; 11428 stocked; 1+ price | verified_datasheet_and_stock
UCA UCB | 2 | PUYA | PY32F030K28U6TR | LCSC | C3018718 | 0.4106 | 0.8212 | 2026-09-09 |  | Lowest-cost specified MCU with verified simultaneous pin map; 18245 stocked; 5+ price | verified_datasheet_and_stock
UCSA UCSB | 2 | Texas Instruments | INA190A3IDDFR | LCSC | C1852076 | 1.8126 | 3.6252 | 2026-09-09 | INA186A3IDDFR | Gain-100 high-side current amplifier with 40 V common-mode range; 8100 stocked; 1+ price | verified_datasheet_and_stock
UBEC | 1 | XLSEMI | XL4016E1 | LCSC | C55881 | 1.0777 | 1.0777 | 2026-09-09 |  | Specified low-cost 5 V high-current buck starting point; 26710 stocked; 1+ price | stock_verified_thermal_validation_required
U12V | 1 | UMW | XL1509-ADJ | LCSC | C2681227 | 0.2219 | 0.2219 | 2026-09-09 |  | Low-cost 40 V input 2 A gate-drive buck; 13060 stocked; 5+ price | stock_verified_datasheet_validation_required
U3V3 | 1 | Torex | XC6206P332MR | LCSC | search-required |  |  |  |  | Specified 3.3 V LDO family; exact stocked suffix to be frozen before order | datasheet_validation_required
RGA1-RGA18 RGB1-RGB18 | 36 | Yageo | RC0603FR-074R7L | Mouser | 603-RC0603FR-074R7L |  |  |  |  | Individual 4.7 ohm 1% gate resistors with globally stocked alternate | verified_family
RPUA1-RPUA6 RPUB1-RPUB6 | 12 | Yageo | RC0603FR-0710KL | Mouser | 603-RC0603FR-0710KL |  |  |  |  | Gate-group pulldown and logic pull resistors | verified_family
CBOOT_A1-CBOOT_A3 CBOOT_B1-CBOOT_B3 | 6 | FH Guo | TCC0603X7R105K500CT | LCSC | search-required |  |  |  |  | 1 uF bootstrap capacitor; exact approved part requires voltage-bias check | validation_required
CBUSA1-CBUSA4 CBUSB1-CBUSB4 | 8 | Panasonic | EEU-FS1V471 | Mouser | 667-EEU-FS1V471 |  |  |  |  | Four 470 uF 35 V low-ESR capacitors per channel starting option | stock_and_fit_validation_required
NTCA1 NTCA2 NTCB1 NTCB2 | 4 | Murata | NCP21XH103J03RA | Mouser | 81-NCP21XH103J03RA |  |  |  |  | 10 kOhm NTC near each shunt and FET bank | verified_family
RDTA RDTB | 2 | Yageo | RC0603FR-07100KL | Mouser | 603-RC0603FR-07100KL |  |  |  |  | DRV8300 variable-deadtime programming starting value; tune from scope results | validation_required
CGVDDA CGVDDB | 2 | Murata | GRM31CR71E106KA12L | Mouser | 81-GRM31CR71E106KA2L |  |  |  |  | 10 uF 25 V X7R local GVDD bypass required by TI | dc_bias_validation_required
CGVDDHF_A CGVDDHF_B | 2 | Murata | GRM188R71E104KA01D | Mouser | 81-GRM188R71E104KA1D |  |  |  |  | 100 nF 25 V local high-frequency GVDD bypass | verified_family
CMCUA1-CMCUA3 CMCUB1-CMCUB3 | 6 | Murata | GRM188R71C104KA01D | Mouser | 81-GRM188R71C104KA1D |  |  |  |  | 100 nF logic decoupling at MCU and analog supply pins | verified_family
CMCUA4 CMCUB4 | 2 | Murata | GRM21BR71A106KE51L | Mouser | 81-GRM21BR71A106KE1L |  |  |  |  | 10 uF local 3.3 V bulk | verified_family
RBEMFT_A1-RBEMFT_A12 RBEMFT_B1-RBEMFT_B12 | 24 | Yageo | RC0603FR-0747KL | Mouser | 603-RC0603FR-0747KL |  |  |  |  | Two series 47 kOhm upper resistors per protected BEMF divider | verified_family
RBEMFB_A1-RBEMFB_A6 RBEMFB_B1-RBEMFB_B6 | 12 | Yageo | RC0603FR-0712KL | Mouser | 603-RC0603FR-0712KL |  |  |  |  | 12 kOhm BEMF divider lower legs; 25.2 V gives 2.85 V nominal | verified_family
RBEMFS_A1-RBEMFS_A6 RBEMFS_B1-RBEMFS_B6 | 12 | Yageo | RC0603FR-071KL | Mouser | 603-RC0603FR-071KL |  |  |  |  | 1 kOhm ADC injection-current limiting resistors | verified_family
CBEMF_A1-CBEMF_A6 CBEMF_B1-CBEMF_B6 | 12 | Murata | GRM1885C1H102JA01D | Mouser | 81-GRM1885C1H102JA1D |  |  |  |  | 1 nF C0G BEMF filter capacitors; tune after ringing capture | verified_family
DBEMF_A1-DBEMF_A3 DBEMF_B1-DBEMF_B3 | 6 | Nexperia | BAT54S | Multiple | validation-required |  |  |  |  | Dual Schottky ADC clamps for BEMF channels | footprint_and_leakage_validation_required
RVBUST_A1-RVBUST_A2 RVBUST_B1-RVBUST_B2 | 4 | Yageo | RC0603FR-0747KL | Mouser | 603-RC0603FR-0747KL |  |  |  |  | Series upper resistors for independent VBUS dividers | verified_family
RVBUSB_A RVBUSB_B | 2 | Yageo | RC0603FR-0712KL | Mouser | 603-RC0603FR-0712KL |  |  |  |  | Lower resistors for independent VBUS dividers | verified_family
RCS_A1 RCS_A2 RCS_B1 RCS_B2 | 4 | Yageo | RC0603FR-0710RL | Mouser | 603-RC0603FR-0710RL |  |  |  |  | 10 ohm INA190 input EMI filter resistors | verified_family
CCS_A CCS_B | 2 | Murata | GRM1885C1H102JA01D | Mouser | 81-GRM1885C1H102JA1D |  |  |  |  | 1 nF differential shunt-input filter | verified_family
CINA_A CINA_B | 2 | Murata | GRM188R71C104KA01D | Mouser | 81-GRM188R71C104KA1D |  |  |  |  | INA190 supply decoupling | verified_family
UOCA UOCB | 2 | Texas Instruments | TLV3201AIDBVR | Mouser | 595-TLV3201AIDBVR |  |  |  |  | Fast comparator from current-amplifier output to TIM1 break | threshold_and_response_validation_required
U12MONA U12MONB | 2 | Texas Instruments | TLV6700DDCR | Mouser | 595-TLV6700DDCR |  |  |  |  | Independent local 12 V gate-supply window monitor; DRV8300 has no nFAULT pin | threshold_validation_required
LBEC | 1 | Bourns | SRP1265A-470M | Mouser | 652-SRP1265A-470M |  |  |  |  | 47 uH shielded BEC inductor starting option | saturation_and_thermal_validation_required
DBEC | 1 | Diodes Incorporated | MBR20100CT | Mouser | 621-MBR20100CT |  |  |  |  | 100 V 20 A dual Schottky BEC catch diode | thermal_validation_required
CBECO1-CBECO4 | 4 | Panasonic | EEH-ZA1A101P | Mouser | 667-EEH-ZA1A101P |  |  |  |  | 100 uF 10 V polymer BEC output bank | ripple_and_stock_validation_required
CBECIN1-CBECIN2 | 2 | Panasonic | EEH-ZA1V101P | Mouser | 667-EEH-ZA1V101P |  |  |  |  | 100 uF 35 V polymer local BEC input bank | ripple_and_stock_validation_required
L12V | 1 | Bourns | SRN8040-680M | Mouser | 652-SRN8040-680M |  |  |  |  | 68 uH shared gate-supply buck inductor | saturation_validation_required
D12V | 1 | Diodes Incorporated | SS36-13-F | Mouser | 621-SS36-F |  |  |  |  | 60 V 3 A Schottky for XL1509 supply | verified_family
CBUSA_HF1-CBUSA_HF6 CBUSB_HF1-CBUSB_HF6 | 12 | Murata | GRM32ER71H106KA12L | Mouser | 81-GRM32ER71H106KA2L |  |  |  |  | 10 uF 50 V MLCC local half-bridge decoupling | dc_bias_validation_required
CSNUBA1-CSNUBA3 CSNUBB1-CSNUBB3 | 6 | Murata | GRM31C5C2J102JA01L | Mouser | 81-GRM31C5C2J102JA1L |  |  |  |  | 1 nF 630 V C0G optional phase snubber capacitors | scope_tuning_required
RSNUBA1-RSNUBA3 RSNUBB1-RSNUBB3 | 6 | Panasonic | ERJ-P06J100V | Mouser | 667-ERJ-P06J100V |  |  |  |  | 10 ohm 0.5 W optional phase snubber resistors | scope_tuning_required
JCTRL | 1 | Molex | 53398-0871 | Mouser | 538-53398-0871 |  |  |  |  | Top-entry 8-pin logic/SPI/SWD control connector | pinout_validation_required

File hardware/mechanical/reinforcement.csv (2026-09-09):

profile | quantity | length_mm | width_mm | thickness_mm | material | status | notes
BAT_RAIL | 4 | 32.0 | 4.0 | 1.0 | C110 copper | preliminary | Two local battery rails per channel; final holes/cutouts follow routed Rev A copper
PHASE_RAIL | 6 | 30.0 | 4.0 | 1.0 | C110 copper | preliminary | One local phase rail per output; final holes/cutouts follow routed Rev A copper

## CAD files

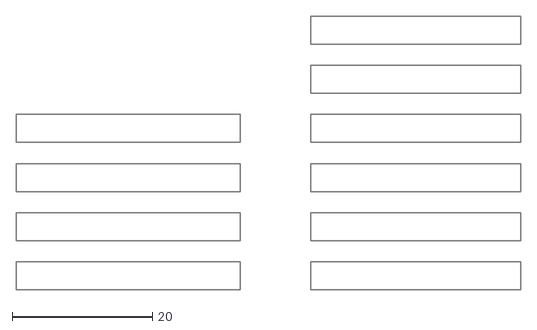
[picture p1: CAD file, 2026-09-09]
hardware/mechanical/reinforcement.dxf
72.0 x 39.0

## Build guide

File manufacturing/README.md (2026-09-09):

# Manufacturing release directory

**No manufacturing release exists yet. Do not order the current CAD.**

`scripts/release.sh` is fail-closed: it first runs the source audit and stops on
placeholder footprints, unresolved sourcing, recorded CAD blockers, missing
validation documents, or policy violations. Only after those conditions are
cleared may it write Gerbers, Excellon drill, front-side CPL, BOM, schematic PDF,
and a SHA-256 manifest here.

The intended fabrication baseline is 98 × 58 mm, four layers, 1.6 mm FR-4, 2 oz
outer / 1 oz inner copper minimum subject to final impedance and thermal review,
ENIG, filled/tented thermal vias where called out, and top-side assembly only.
High-current testing additionally requires the approved CNC copper reinforcement
set and external star-split 8-AWG battery leads.

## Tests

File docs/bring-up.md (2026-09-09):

# Staged bring-up

Every stage requires an isolated bench, eye protection, a restrained motor,
remote emergency stop, current-limited source, and no loose objects near an EDF.
Record results and artifact hashes in `validation/ledger.csv`.

1. **Unpowered inspection:** verify polarity, isolation between A/B power paths,
   shunt Kelvin boundaries, solder bridges, busbar clearance, and resistance from
   every gate to source. Stop on any unexpected low resistance.
2. **Gate-only power:** omit battery links and power the 12 V/3.3 V rails from
   limited supplies. Verify all six outputs remain off through reset and watchdog,
   then measure high/low gate amplitude and deadtime into dummy capacitive loads.
3. **Low-voltage switching:** use ≤12 V and ≤2 A with an inductive dummy load.
   Capture every switch node, bootstrap voltage, gate-source voltage, ringing,
   and hardware-break latency. Stop for shoot-through, >55 V inferred overshoot,
   unequal parallel-gate behavior, or any reset.
4. **3S motor:** mechanically restrain one motor, one channel at a time, ≤10 A.
   Verify align/ramp, all six BEMF traces, zero-cross handoff, throttle timeout,
   stall handling, and emergency stop.
5. **Restricted 6S:** install approved busbars, begin ≤20 A, and raise load only
   after shunt calibration and thermal soak at the preceding point. Repeat both
   channels separately before simultaneous auxiliary-only operation.
6. **Envelope characterization:** increase current in small steps with logged
   MOSFET/PCB/shunt/capacitor/BEC temperatures and scope captures. The 150 A
   value remains inaccessible until a reviewed safe-operating envelope exists.

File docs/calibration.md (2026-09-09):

# Current and voltage calibration

Use a traceable four-wire reference shunt and meter. Do not infer calibration
from PCB geometry alone.

For each channel, force 0 A and store the averaged INA190 ADC offset. Apply at
least five current points over the permitted low-power range in both directions
where the setup allows it. Fit `I = gain × (ADC - offset)` and record residual,
temperature, reference-shunt certificate, supply voltage, operator, and firmware
hash. Reject calibration if any point differs by more than 3% before full-power
work.

Measure the Kelvin-to-Kelvin PCB-shunt voltage independently to obtain actual
resistance. Record cold resistance and resistance after thermal equilibrium.
The starting copper coefficient is 0.0039/K, but compensation remains disabled
until measured temperature correlation supports it.

Calibrate VBUS at 3S, 4S, 5S, and 6S-equivalent bench voltages below the source
current limit. Verify the raw ADC node stays below the MCU absolute maximum under
captured switching overshoot, including clamp current through the 1 kΩ series
resistor.

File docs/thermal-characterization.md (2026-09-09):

# Thermal characterization

Characterize one channel first, then both auxiliaries, and only then consider two
motors. Use thermocouples on representative high/low MOSFET cases, PCB beneath
each bank, shunt, bulk capacitors, XL4016, catch diode, BEC inductor, 12 V supply,
and both busbar joints. An IR camera is supplementary; emissivity errors do not
replace contact measurements.

At each current point hold until temperature slope remains below 1 °C over five
minutes or an abort limit is reached. Record airflow and ambient temperature.
Abort on 100 °C PCB/NTC, 90 °C electrolytic case, 110 °C inductor/catch diode,
unexpected >10 °C spread among parallel MOSFETs, worsening ringing, calibration
drift >3%, or any protection event.

Test the BEC separately at 2, 4, 6, then 8 A with 6S input. Log input/output power,
ripple, inductor and diode case temperature, and shutdown behavior. Eight amperes
is a characterization target, not a continuous rating, until this record passes.

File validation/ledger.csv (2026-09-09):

stage | channel | date | operator | hardware_commit | firmware_commit | supply_limit | load | ambient_c | max_temp_c | scope_artifacts | result | notes
unpowered | A |  |  |  |  |  |  |  |  |  | pending
unpowered | B |  |  |  |  |  |  |  |  |  | pending
gate_only | A |  |  |  |  |  |  |  |  |  | pending
gate_only | B |  |  |  |  |  |  |  |  |  | pending
low_voltage | A |  |  |  |  |  |  |  |  |  | pending
low_voltage | B |  |  |  |  |  |  |  |  |  | pending
3s_motor | A |  |  |  |  |  |  |  |  |  | pending
3s_motor | B |  |  |  |  |  |  |  |  |  | pending
restricted_6s | A |  |  |  |  |  |  |  |  |  | pending
restricted_6s | B |  |  |  |  |  |  |  |  |  | pending
bec_2_4_6_8a | shared |  |  |  |  |  |  |  |  |  | pending

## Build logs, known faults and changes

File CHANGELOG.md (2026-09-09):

# Changelog

## Unreleased

- Freeze the dual-channel architecture, verified QFN-32 pin map, and initial BOM.
- Add reproducible electrical/thermal starting calculations.
- Add host-tested control, sensorless, protection, and SPI protocol cores.
- Add deterministic KiCad placement prototype accepted by the KiCad 7 parser.
- Record open DRC, schematic, footprint, target-build, sourcing, and physical
  validation blockers without claiming a fabrication release.

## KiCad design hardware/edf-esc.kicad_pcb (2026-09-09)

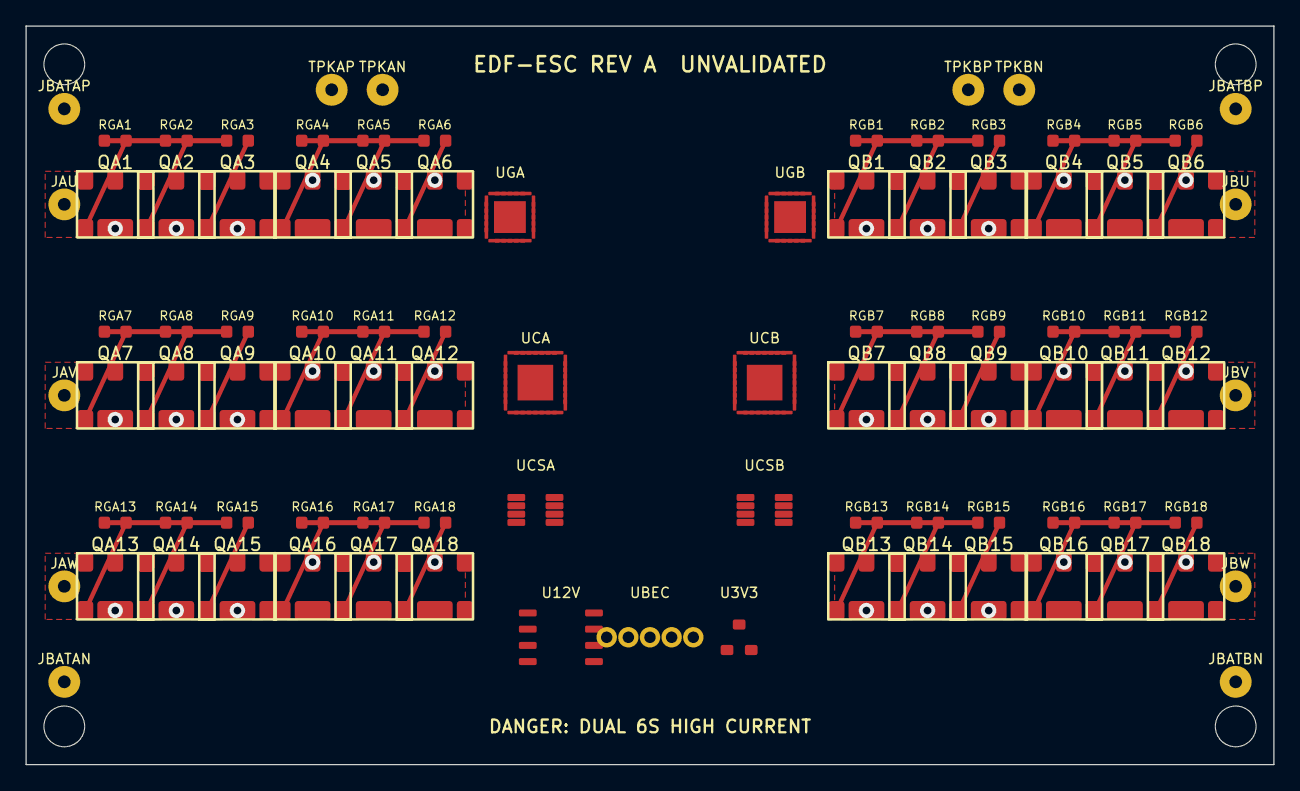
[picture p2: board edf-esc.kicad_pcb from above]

Board: 4 copper layers, 98.0 x 58.0 mm, 99 parts (0 on the bottom side), 83 nets.

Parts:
H1, H2, H3, H4: M3; M3_NPTH
JAU: MOTOR_A_U; TESTPAD_2MM
JAV: MOTOR_A_V; TESTPAD_2MM
JAW: MOTOR_A_W; TESTPAD_2MM
JBATAN: BAT_A-; TESTPAD_2MM
JBATAP: BAT_A+; TESTPAD_2MM
JBATBN: BAT_B-; TESTPAD_2MM
JBATBP: BAT_B+; TESTPAD_2MM
JBU: MOTOR_B_U; TESTPAD_2MM
JBV: MOTOR_B_V; TESTPAD_2MM
JBW: MOTOR_B_W; TESTPAD_2MM
QA1, QA2, QA3, QA4, QA5, QA6, QA7, QA8, QA9, QA10, QA11, QA12, QA13, QA14, QA15, QA16, QA17, QA18: SFS06R025GF; PDFN56
QB1, QB2, QB3, QB4, QB5, QB6, QB7, QB8, QB9, QB10, QB11, QB12, QB13, QB14, QB15, QB16, QB17, QB18: SFS06R025GF; PDFN56
RGA1, RGA2, RGA3, RGA4, RGA5, RGA6, RGA7, RGA8, RGA9, RGA10, RGA11, RGA12, RGA13, RGA14, RGA15, RGA16, RGA17, RGA18: 4R7; R_0603
RGB1, RGB2, RGB3, RGB4, RGB5, RGB6, RGB7, RGB8, RGB9, RGB10, RGB11, RGB12, RGB13, RGB14, RGB15, RGB16, RGB17, RGB18: 4R7; R_0603
TPKAN: KELVIN_A-; TESTPAD_2MM
TPKAP: KELVIN_A+; TESTPAD_2MM
TPKBN: KELVIN_B-; TESTPAD_2MM
TPKBP: KELVIN_B+; TESTPAD_2MM
U3V3: XC6206P332MR; SOT23-3
U12V: XL1509-ADJ; SOIC8
UBEC: XL4016E1; TO220-5
UCA: PY32F030K28U6TR; QFN32
UCB: PY32F030K28U6TR; QFN32
UCSA: INA190A3IDDFR; TSOT23-8
UCSB: INA190A3IDDFR; TSOT23-8
UGA: DRV8300DRGER; QFN24
UGB: DRV8300DRGER; QFN24

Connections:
12V_GATE: UGA.4, UGB.4
12V_SW: U12V.1, U12V.2
+3V3: U3V3.2, UCA.1, UCB.1, UCSA.1, UCSA.2, UCSB.1, UCSB.2
BAT_A+: JBATAP.1, QA1.5, QA1.6, QA1.7, QA1.8, QA2.5, QA2.6, QA2.7, QA2.8, QA3.5, QA3.6, QA3.7, QA3.8, QA7.5, QA7.6, QA7.7, QA7.8, QA8.5, QA8.6, QA8.7, QA8.8, QA9.5, QA9.6, QA9.7, QA9.8, QA13.5, QA13.6, QA13.7, QA13.8, QA14.5, QA14.6, QA14.7, QA14.8, QA15.5, QA15.6, QA15.7, QA15.8, U12V.6, U12V.7, UBEC.4
BAT_A-: JBATAN.1, QA4.1, QA4.2, QA4.3, QA5.1, QA5.2, QA5.3, QA6.1, QA6.2, QA6.3, QA10.1, QA10.2, QA10.3, QA11.1, QA11.2, QA11.3, QA12.1, QA12.2, QA12.3, QA16.1, QA16.2, QA16.3, QA17.1, QA17.2, QA17.3, QA18.1, QA18.2, QA18.3
BAT_B+: JBATBP.1, QB1.5, QB1.6, QB1.7, QB1.8, QB2.5, QB2.6, QB2.7, QB2.8, QB3.5, QB3.6, QB3.7, QB3.8, QB7.5, QB7.6, QB7.7, QB7.8, QB8.5, QB8.6, QB8.7, QB8.8, QB9.5, QB9.6, QB9.7, QB9.8, QB13.5, QB13.6, QB13.7, QB13.8, QB14.5, QB14.6, QB14.7, QB14.8, QB15.5, QB15.6, QB15.7, QB15.8
BAT_B-: JBATBN.1, QB4.1, QB4.2, QB4.3, QB5.1, QB5.2, QB5.3, QB6.1, QB6.2, QB6.3, QB10.1, QB10.2, QB10.3, QB11.1, QB11.2, QB11.3, QB12.1, QB12.2, QB12.3, QB16.1, QB16.2, QB16.3, QB17.1, QB17.2, QB17.3, QB18.1, QB18.2, QB18.3
CURRENT_A: UCA.6, UCSA.5
CURRENT_B: UCB.6, UCSB.5
GND: U3V3.1, U12V.4, UBEC.1, UCA.16, UCA.31, UCA.33, UCB.16, UCB.31, UCB.33, UCSA.3, UCSA.4, UCSB.3, UCSB.4, UGA.5, UGA.6, UGA.25, UGB.5, UGB.6, UGB.25
G_A_UH: RGA1.1, RGA2.1, RGA3.1, UGA.19
G_A_UH_1: QA1.4, RGA1.2
G_A_UH_2: QA2.4, RGA2.2
G_A_UH_3: QA3.4, RGA3.2
G_A_UL: RGA4.1, RGA5.1, RGA6.1, UGA.11
G_A_UL_1: QA4.4, RGA4.2
G_A_UL_2: QA5.4, RGA5.2
G_A_UL_3: QA6.4, RGA6.2
G_A_VH: RGA7.1, RGA8.1, RGA9.1, UGA.16
G_A_VH_1: QA7.4, RGA7.2
G_A_VH_2: QA8.4, RGA8.2
G_A_VH_3: QA9.4, RGA9.2
G_A_VL: RGA10.1, RGA11.1, RGA12.1, UGA.10
G_A_VL_1: QA10.4, RGA10.2
G_A_VL_2: QA11.4, RGA11.2
G_A_VL_3: QA12.4, RGA12.2
G_A_WH: RGA13.1, RGA14.1, RGA15.1, UGA.13
G_A_WH_1: QA13.4, RGA13.2
G_A_WH_2: QA14.4, RGA14.2
G_A_WH_3: QA15.4, RGA15.2
G_A_WL: RGA16.1, RGA17.1, RGA18.1, UGA.9
G_A_WL_1: QA16.4, RGA16.2
G_A_WL_2: QA17.4, RGA17.2
G_A_WL_3: QA18.4, RGA18.2
G_B_UH: RGB1.1, RGB2.1, RGB3.1, UGB.19
G_B_UH_1: QB1.4, RGB1.2
G_B_UH_2: QB2.4, RGB2.2
G_B_UH_3: QB3.4, RGB3.2
G_B_UL: RGB4.1, RGB5.1, RGB6.1, UGB.11
G_B_UL_1: QB4.4, RGB4.2
G_B_UL_2: QB5.4, RGB5.2
G_B_UL_3: QB6.4, RGB6.2
G_B_VH: RGB7.1, RGB8.1, RGB9.1, UGB.16
G_B_VH_1: QB7.4, RGB7.2
G_B_VH_2: QB8.4, RGB8.2
G_B_VH_3: QB9.4, RGB9.2
G_B_VL: RGB10.1, RGB11.1, RGB12.1, UGB.10
G_B_VL_1: QB10.4, RGB10.2
G_B_VL_2: QB11.4, RGB11.2
G_B_VL_3: QB12.4, RGB12.2
G_B_WH: RGB13.1, RGB14.1, RGB15.1, UGB.13
G_B_WH_1: QB13.4, RGB13.2
G_B_WH_2: QB14.4, RGB14.2
G_B_WH_3: QB15.4, RGB15.2
G_B_WL: RGB16.1, RGB17.1, RGB18.1, UGB.9
G_B_WL_1: QB16.4, RGB16.2
G_B_WL_2: QB17.4, RGB17.2
G_B_WL_3: QB18.4, RGB18.2
KELVIN_A+: TPKAP.1, UCSA.7
KELVIN_A-: TPKAN.1, UCSA.8
KELVIN_B+: TPKBP.1, UCSB.7
KELVIN_B-: TPKBN.1, UCSB.8
MOTOR_A_U: JAU.1, QA1.1, QA1.2, QA1.3, QA2.1, QA2.2, QA2.3, QA3.1, QA3.2, QA3.3, QA4.5, QA4.6, QA4.7, QA4.8, QA5.5, QA5.6, QA5.7, QA5.8, QA6.5, QA6.6, QA6.7, QA6.8, UGA.18
MOTOR_A_V: JAV.1, QA7.1, QA7.2, QA7.3, QA8.1, QA8.2, QA8.3, QA9.1, QA9.2, QA9.3, QA10.5, QA10.6, QA10.7, QA10.8, QA11.5, QA11.6, QA11.7, QA11.8, QA12.5, QA12.6, QA12.7, QA12.8, UGA.15
MOTOR_A_W: JAW.1, QA13.1, QA13.2, QA13.3, QA14.1, QA14.2, QA14.3, QA15.1, QA15.2, QA15.3, QA16.5, QA16.6, QA16.7, QA16.8, QA17.5, QA17.6, QA17.7, QA17.8, QA18.5, QA18.6, QA18.7, QA18.8, UGA.12
MOTOR_B_U: JBU.1, QB1.1, QB1.2, QB1.3, QB2.1, QB2.2, QB2.3, QB3.1, QB3.2, QB3.3, QB4.5, QB4.6, QB4.7, QB4.8, QB5.5, QB5.6, QB5.7, QB5.8, QB6.5, QB6.6, QB6.7, QB6.8, UGB.18
MOTOR_B_V: JBV.1, QB7.1, QB7.2, QB7.3, QB8.1, QB8.2, QB8.3, QB9.1, QB9.2, QB9.3, QB10.5, QB10.6, QB10.7, QB10.8, QB11.5, QB11.6, QB11.7, QB11.8, QB12.5, QB12.6, QB12.7, QB12.8, UGB.15
MOTOR_B_W: JBW.1, QB13.1, QB13.2, QB13.3, QB14.1, QB14.2, QB14.3, QB15.1, QB15.2, QB15.3, QB16.5, QB16.6, QB16.7, QB16.8, QB17.5, QB17.6, QB17.7, QB17.8, QB18.5, QB18.6, QB18.7, QB18.8, UGB.12
PWM_A_UH: UCA.18, UGA.22
PWM_A_UL: UCA.13, UGA.1
PWM_A_VH: UCA.19, UGA.23
PWM_A_VL: UCA.14, UGA.2
PWM_A_WH: UCA.20, UGA.24
PWM_A_WL: UCA.15, UGA.3
PWM_B_UH: UCB.18, UGB.22
PWM_B_UL: UCB.13, UGB.1
PWM_B_VH: UCB.19, UGB.23
PWM_B_VL: UCB.14, UGB.2
PWM_B_WH: UCB.20, UGB.24
PWM_B_WL: UCB.15, UGB.3
SPI_MISO: UCA.3, UCB.3
SPI_MOSI: UCA.30, UCB.30
SPI_SCK: UCA.2, UCB.2

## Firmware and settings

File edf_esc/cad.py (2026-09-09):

"""Deterministic KiCad source generation for the review prototype.

The generated PCB is intentionally source-controlled: regeneration is tested byte
for byte so manufacturing plots can always be traced to reviewed Python inputs.
"""

from __future__ import annotations

import re
from pathlib import Path

BOARD_VERSION = 20221018
SCHEMATIC_VERSION = 20230121


def _qfn_fet(ref: str, x: float, y: float, gate: str, source: str, drain: str,
             nets: dict[str, int]) -> str:
    pads = []
    for number, px, py, net in (
        (1, -2.35, -1.90, source), (2, 0, -1.90, source), (3, 2.35, -1.90, source),
        (4, -2.35, 1.90, gate), (5, -0.78, 1.90, drain), (6, 0, 1.90, drain),
        (7, 0.78, 1.90, drain), (8, 2.35, 1.90, drain),
    ):
        pads.append(
            f'    (pad "{number}" smd roundrect (at {px:.2f} {py:.2f}) '
            f'(size 1.25 1.5) (layers "F.Cu" "F.Paste" "F.Mask") '
            f'(roundrect_rratio 0.2) (net {nets[net]} "{net}"))'
        )
    return "\n".join([
        f'  (footprint "EDF_ESC:PDFN56" (layer "F.Cu") (at {x:.2f} {y:.2f})',
        f'    (fp_text reference "{ref}" (at 0 -3.3 0) (layer "F.SilkS") (effects (font (size 1 1) (thickness 0.15))))',
        '    (fp_text value "SFS06R025GF" (at 0 3.3 0) (layer "F.Fab") (effects (font (size 1 1) (thickness 0.15))))',
        '    (attr smd)',
        '    (fp_rect (start -3 -2.6) (end 3 2.6) (stroke (width 0.2) (type default)) (fill none) (layer "F.SilkS"))',
        *pads,
        '  )',
    ])


def _resistor(ref: str, x: float, y: float, left: str, right: str,
              nets: dict[str, int]) -> str:
    return f'''  (footprint "EDF_ESC:R_0603" (layer "F.Cu") (at {x:.2f} {y:.2f})
    (fp_text reference "{ref}" (at 0 -1.25 0) (layer "F.SilkS") (effects (font (size 0.7 0.7) (thickness 0.1))))
    (fp_text value "4R7" (at 0 1.25 0) (layer "F.Fab") (effects (font (size 0.7 0.7) (thickness 0.1))))
    (attr smd)
    (pad "1" smd roundrect (at -0.85 0) (size 0.9 0.95) (layers "F.Cu" "F.Paste" "F.Mask") (roundrect_rratio 0.2) (net {nets[left]} "{left}"))
    (pad "2" smd roundrect (at 0.85 0) (size 0.9 0.95) (layers "F.Cu" "F.Paste" "F.Mask") (roundrect_rratio 0.2) (net {nets[right]} "{right}"))
  )'''


def _testpad(ref: str, x: float, y: float, net: str, nets: dict[str, int]) -> str:
    return f'''  (footprint "EDF_ESC:TESTPAD_2MM" (layer "F.Cu") (at {x:.2f} {y:.2f})
    (fp_text reference "{ref}" (at 0 -1.8 0) (layer "F.SilkS") (effects (font (size 0.8 0.8) (thickness 0.12))))
    (fp_text value "{net}" (at 0 1.8 0) (layer "F.Fab") (effects (font (size 0.8 0.8) (thickness 0.12))))
    (attr exclude_from_pos_files)
    (pad "1" thru_hole circle (at 0 0) (size 2.5 2.5) (drill 1.0) (layers "*.Cu" "*.Mask") (net {nets[net]} "{net}"))
  )'''


def _device(ref: str, value: str, package: str, x: float, y: float,
            pad_nets: list[str | None], nets: dict[str, int]) -> str:
    count = len(pad_nets)
    pads: list[str] = []
    if package.startswith("QFN"):
        perimeter = count - 1
        per_side = perimeter // 4
        positions: list[tuple[float, float, float]] = []
        for i in range(per_side):
            offset = -((per_side - 1) * 0.5) * 0.5 + i * 0.5
            positions.append((-2.35 if perimeter == 32 else -1.85, -offset, 90))
        for i in range(per_side):
            offset = -((per_side - 1) * 0.5) * 0.5 + i * 0.5
            positions.append((offset, -2.35 if perimeter == 32 else -1.85, 0))
        for i in range(per_side):
            offset = -((per_side - 1) * 0.5) * 0.5 + i * 0.5
            positions.append((2.35 if perimeter == 32 else 1.85, offset, 90))
        for i in range(per_side):
            offset = -((per_side - 1) * 0.5) * 0.5 + i * 0.5
            positions.append((-offset, 2.35 if perimeter == 32 else 1.85, 0))
        positions.append((0, 0, 0))
        for number, ((px, py, angle), net) in enumerate(zip(positions, pad_nets), 1):
            size = "2.8 2.8" if number == count and perimeter == 32 else ("2.5 2.5" if number == count else "0.9 0.28")
            shape = "rect" if number == count else "roundrect"
            rr = " (roundrect_rratio 0.2)" if shape == "roundrect" else ""
            net_clause = f' (net {nets[net]} "{net}")' if net else ""
            pads.append(f'    (pad "{number}" smd {shape} (at {px:.2f} {py:.2f} {angle}) (size {size}) (layers "F.Cu" "F.Paste" "F.Mask"){rr}{net_clause})')
        body = 5.0 if perimeter == 32 else 4.0
    elif package == "SOIC8" or package == "TSOT23-8":
        pitch = 1.27 if package == "SOIC8" else 0.65
        row_x = 2.6 if package == "SOIC8" else 1.5
        positions = [(-row_x, (i - 1.5) * pitch, 0) for i in range(4)] + [(row_x, (1.5 - i) * pitch, 0) for i in range(4)]
        for number, ((px, py, angle), net) in enumerate(zip(positions, pad_nets), 1):
            net_clause = f' (net {nets[net]} "{net}")' if net else ""
            pads.append(f'    (pad "{number}" smd roundrect (at {px:.2f} {py:.2f} {angle}) (size 1.4 0.55) (layers "F.Cu" "F.Paste" "F.Mask") (roundrect_rratio 0.2){net_clause})')
        body = 4.0 if package == "SOIC8" else 3.0
    elif package == "SOT23-3":
        positions = [(-0.95, 1.0, 0), (0.95, 1.0, 0), (0, -1.0, 0)]
        for number, ((px, py, angle), net) in enumerate(zip(positions, pad_nets), 1):
            net_clause = f' (net {nets[net]} "{net}")' if net else ""
            pads.append(f'    (pad "{number}" smd roundrect (at {px:.2f} {py:.2f} {angle}) (size 1.0 0.8) (layers "F.Cu" "F.Paste" "F.Mask") (roundrect_rratio 0.2){net_clause})')
        body = 3.0
    elif package == "TO220-5":
        positions = [((i - 2) * 1.7, 0, 0) for i in range(5)]
        for number, ((px, py, angle), net) in enumerate(zip(positions, pad_nets), 1):
            net_clause = f' (net {nets[net]} "{net}")' if net else ""
            pads.append(f'    (pad "{number}" thru_hole circle (at {px:.2f} {py:.2f} {angle}) (size 1.6 1.6) (drill 0.9) (layers "*.Cu" "*.Mask"){net_clause})')
        body = 10.0
    else:
        raise ValueError(package)
    return "\n".join([
        f'  (footprint "EDF_ESC:{package}" (layer "F.Cu") (at {x:.2f} {y:.2f})',
        f'    (fp_text reference "{ref}" (at 0 -3.5 0) (layer "F.SilkS") (effects (font (size 0.8 0.8) (thickness 0.12))))',
        f'    (fp_text value "{value}" (at 0 3.5 0) (layer "F.Fab") (effects (font (size 0.8 0.8) (thickness 0.12))))',
        '    (attr smd)',
        f'    (fp_rect (start {-body/2:.2f} {-body/2:.2f}) (end {body/2:.2f} {body/2:.2f}) (stroke (width 0.15) (type default)) (fill none) (layer "F.Fab"))',
        *pads,
        '  )',
    ])


def build_board() -> str:
    fixed_nets = [
        "GND", "BAT_A+", "BAT_A-", "MOTOR_A_U", "MOTOR_A_V", "MOTOR_A_W",
        "BAT_B+", "BAT_B-", "MOTOR_B_U", "MOTOR_B_V", "MOTOR_B_W",
        "12V_GATE", "5V_BEC", "+3V3", "KELVIN_A+", "KELVIN_A-",
        "KELVIN_B+", "KELVIN_B-", "TIM1_BKIN_A", "TIM1_BKIN_B",
    ]
    gate_groups = [f"G_{ch}_{phase}{side}" for ch in "AB" for phase in "UVW" for side in "HL"]
    gate_pads = [f"{group}_{n}" for group in gate_groups for n in range(1, 4)]
    bemf = [f"BEMF_{ch}_{phase}" for ch in "AB" for phase in "UVW"]
    controls = [f"PWM_{ch}_{phase}{side}" for ch in "AB" for phase in "UVW" for side in "HL"]
    bootstrap = [f"BST_{ch}_{phase}" for ch in "AB" for phase in "UVW"]
    sensed = [f"CURRENT_{ch}" for ch in "AB"] + [f"VBUS_ADC_{ch}" for ch in "AB"] + [f"NTC_{ch}" for ch in "AB"]
    interfaces = ["SPI_SCK", "SPI_MOSI", "SPI_MISO", "CS_A", "CS_B", "THROTTLE_A", "THROTTLE_B", "SWDIO_A", "SWCLK_A", "SWDIO_B", "SWCLK_B", "NRST_A", "NRST_B", "GATE_SUPPLY_FAULT_A", "GATE_SUPPLY_FAULT_B", "BEC_SW", "BEC_FB", "12V_SW", "12V_FB"]
    names = fixed_nets + gate_groups + gate_pads + bemf + controls + bootstrap + sensed + interfaces
    nets = {name: i + 1 for i, name in enumerate(names)}
    out = [
        f'(kicad_pcb (version {BOARD_VERSION}) (generator pcbnew)',
        '  (general (thickness 1.6))',
        '  (paper "A4")',
        '  (layers',
        '    (0 "F.Cu" signal)',
        '    (2 "In1.Cu" power)',
        '    (4 "In2.Cu" power)',
        '    (31 "B.Cu" signal)',
        '    (36 "B.SilkS" user "b.silkscreen")',
        '    (37 "F.SilkS" user "f.silkscreen")',
        '    (44 "Edge.Cuts" user)',
        '  )',
        '  (setup (pad_to_mask_clearance 0))',
        *[f'  (net {number} "{name}")' for name, number in nets.items()],
        '  (gr_rect (start 0 0) (end 98 58) (stroke (width 0.1) (type default)) (fill none) (layer "Edge.Cuts"))',
        '  (gr_text "EDF-ESC REV A  UNVALIDATED" (at 49 3) (layer "F.SilkS") (effects (font (size 1.2 1.2) (thickness 0.2))))',
        '  (gr_text "DANGER: DUAL 6S HIGH CURRENT" (at 49 55) (layer "F.SilkS") (effects (font (size 1 1) (thickness 0.18))))',
    ]

    groups = [("U", "H"), ("U", "L"), ("V", "H"), ("V", "L"), ("W", "H"), ("W", "L")]
    for ch, x0 in (("A", 7.0), ("B", 66.0)):
        batp, batm = f"BAT_{ch}+", f"BAT_{ch}-"
        for group_index, (phase, side) in enumerate(groups):
            row, column = divmod(group_index, 2)
            source = f"MOTOR_{ch}_{phase}" if side == "H" else batm
            drain = batp if side == "H" else f"MOTOR_{ch}_{phase}"
            group_gate = f"G_{ch}_{phase}{side}"
            for parallel in range(3):
                ordinal = group_index * 3 + parallel + 1
                x = x0 + column * 15.5 + parallel * 4.8
                y = 14.0 + row * 15.0
                fet_gate = f"{group_gate}_{parallel + 1}"
                out.append(_qfn_fet(f"Q{ch}{ordinal}", x, y, fet_gate, source, drain, nets))
                out.append(_resistor(f"RG{ch}{ordinal}", x, y - 5.0, group_gate, fet_gate, nets))
                out.append(f'  (segment (start {x + 0.85:.2f} {y - 5:.2f}) (end {x - 2.35:.2f} {y + 1.90:.2f}) (width 0.35) (layer "F.Cu") (net {nets[fet_gate]}))')
                if parallel:
                    out.append(f'  (segment (start {x - 5.65:.2f} {y - 5:.2f}) (end {x - 0.85:.2f} {y - 5:.2f}) (width 0.4) (layer "F.Cu") (net {nets[group_gate]}))')
                power_net = drain if side == "H" else source
                power_pad_y = y + 1.90 if side == "H" else y - 1.90
                out.append(f'  (via (at {x:.2f} {power_pad_y:.2f}) (size 1.2) (drill 0.6) (layers "F.Cu" "B.Cu") (net {nets[power_net]}))')

        edge_x = 3.0 if ch == "A" else 95.0
        for phase, y in zip("UVW", (14.0, 29.0, 44.0)):
            out.append(_testpad(f"J{ch}{phase}", edge_x, y, f"MOTOR_{ch}_{phase}", nets))
            zone_x1, zone_x2 = ((1.5, 34.5) if ch == "A" else (63.5, 96.5))
            phase_net = f"MOTOR_{ch}_{phase}"
            out.append(f'''  (zone (net {nets[phase_net]}) (net_name "{phase_net}") (layer "F.Cu") (hatch edge 0.5)
    (connect_pads (clearance 0.4)) (min_thickness 0.25) (fill yes (thermal_gap 0.5) (thermal_bridge_width 0.8))
    (polygon (pts (xy {zone_x1} {y - 2.6}) (xy {zone_x2} {y - 2.6}) (xy {zone_x2} {y + 2.6}) (xy {zone_x1} {y + 2.6})))
  )''')
        out.append(_testpad(f"JBAT{ch}P", edge_x, 6.5, batp, nets))
        out.append(_testpad(f"JBAT{ch}N", edge_x, 51.5, batm, nets))
        kelvin_x = 24.0 if ch == "A" else 74.0
        out.append(_testpad(f"TPK{ch}P", kelvin_x, 5.0, f"KELVIN_{ch}+", nets))
        out.append(_testpad(f"TPK{ch}N", kelvin_x + 4.0, 5.0, f"KELVIN_{ch}-", nets))

    # The centre is deliberately kept low-current and clear of phase copper.
    for ch, x in (("A", 38.0), ("B", 60.0)):
        driver_pins = [
            f"PWM_{ch}_UL", f"PWM_{ch}_VL", f"PWM_{ch}_WL", "12V_GATE", "GND", "GND", None, None,
            f"G_{ch}_WL", f"G_{ch}_VL", f"G_{ch}_UL", f"MOTOR_{ch}_W", f"G_{ch}_WH", f"BST_{ch}_W",
            f"MOTOR_{ch}_V", f"G_{ch}_VH", f"BST_{ch}_V", f"MOTOR_{ch}_U", f"G_{ch}_UH", f"BST_{ch}_U",
            None, f"PWM_{ch}_UH", f"PWM_{ch}_VH", f"PWM_{ch}_WH", "GND",
        ]
        out.append(_device(f"UG{ch}", "DRV8300DRGER", "QFN24", x, 15.0, driver_pins, nets))
        mcu_pins = [
            "+3V3", "SPI_SCK", "SPI_MISO", f"NRST_{ch}", None, f"CURRENT_{ch}", f"VBUS_ADC_{ch}", f"BEMF_{ch}_U",
            f"BEMF_{ch}_V", f"BEMF_{ch}_W", f"NTC_{ch}", f"TIM1_BKIN_{ch}", f"PWM_{ch}_UL", f"PWM_{ch}_VL",
            f"PWM_{ch}_WL", "GND", None, f"PWM_{ch}_UH", f"PWM_{ch}_VH", f"PWM_{ch}_WH", None, None,
            f"SWDIO_{ch}", f"SWCLK_{ch}", None, None, f"THROTTLE_{ch}", f"GATE_SUPPLY_FAULT_{ch}", None, "SPI_MOSI", "GND", f"CS_{ch}", "GND",
        ]
        out.append(_device(f"UC{ch}", "PY32F030K28U6TR", "QFN32", 40.0 if ch == "A" else 58.0, 28.0, mcu_pins, nets))
        ina_pins = ["+3V3", "+3V3", "GND", "GND", f"CURRENT_{ch}", None, f"KELVIN_{ch}+", f"KELVIN_{ch}-"]
        out.append(_device(f"UCS{ch}", "INA190A3IDDFR", "TSOT23-8", 40.0 if ch == "A" else 58.0, 38.0, ina_pins, nets))
    out.append(_device("U12V", "XL1509-ADJ", "SOIC8", 42.0, 48.0,
                       ["12V_SW", "12V_SW", "12V_FB", "GND", None, "BAT_A+", "BAT_A+", None], nets))
    out.append(_device("UBEC", "XL4016E1", "TO220-5", 49.0, 48.0,
                       ["GND", "BEC_FB", "BEC_SW", "BAT_A+", None], nets))
    out.append(_device("U3V3", "XC6206P332MR", "SOT23-3", 56.0, 48.0,
                       ["GND", "+3V3", "5V_BEC"], nets))

    # Four mounting holes, all populated from the top side.
    for index, (x, y) in enumerate(((3, 3), (95, 3), (3, 55), (95, 55)), 1):
        out.append(f'''  (footprint "EDF_ESC:M3_NPTH" (layer "F.Cu") (at {x} {y})
    (fp_text reference "H{index}" (at 0 -3 0) (layer "F.SilkS") hide (effects (font (size 1 1) (thickness 0.15))))
    (fp_text value "M3" (at 0 3 0) (layer "F.Fab") hide (effects (font (size 1 1) (thickness 0.15))))
    (attr exclude_from_pos_files exclude_from_bom)
    (pad "" np_thru_hole circle (at 0 0) (size 3.2 3.2) (drill 3.2) (layers "*.Cu" "*.Mask"))
  )''')

    # Named high-current zones make branch separation inspectable in KiCad.
    for ch, x1, x2 in (("A", 1.5, 39.0), ("B", 59.0, 96.5)):
        for layer, net in (("In1.Cu", f"BAT_{ch}-"), ("In2.Cu", f"BAT_{ch}+")):
            out.append(f'''  (zone (net {nets[net]}) (net_name "{net}") (layer "{layer}") (hatch edge 0.5)
    (connect_pads (clearance 0.5)) (min_thickness 0.25) (fill yes (thermal_gap 0.5) (thermal_bridge_width 0.8))
    (polygon (pts (xy {x1} 5) (xy {x2} 5) (xy {x2} 53) (xy {x1} 53)))
  )''')
    out.append(')')
    return "\n".join(out) + "\n"


def build_schematic() -> str:
    # Keep the complete symbol library in the schematic so it opens without
    # relying on a user's global library table.  Every connection is a real
    # label attached to a real symbol pin (the review sheet is not a netlist
    # disguised as prose).
    library = build_symbol_library().splitlines()[1:-1]
    lines = [f'(kicad_sch (version {SCHEMATIC_VERSION}) (generator eeschema)',
             '  (uuid 3e5b24b0-462c-4f73-9fb1-36e521559001)', '  (paper "A4")',
             '  (lib_symbols']
    lines.extend('  ' + line for line in library)
    lines.append('  )')
    instances: list[tuple[str, str, float, float]] = []
    for ch, x in (("A", 55.0), ("B", 175.0)):
        instances += [(f"UG{ch}", "DRV8300DRGER", x, 55),
                      (f"UC{ch}", "PY32F030K28U6TR", x, 125),
                      (f"UCS{ch}", "INA190A3IDDFR", x, 195)]
        for i in range(18):
            instances.append((f"Q{ch}{i+1}", "SFS06R025GF", x + (i % 6) * 12, 255 + (i // 6) * 22))
            instances.append((f"RG{ch}{i+1}", "R_0603", x + (i % 6) * 12, 245 + (i // 6) * 22))
    instances += [("U12V", "XL1509-ADJ", 150, 255), ("UBEC", "XL4016E1", 175, 255),
                  ("U3V3", "XC6206P332MR", 200, 255)]
    for n, (ref, value, x, y) in enumerate(instances, 1):
        uid = f"3e5b24b0-462c-4f73-9fb1-{n:012d}"
        display_value = "4R7" if value == "R_0603" else value
        lines += [f'  (symbol (lib_id "EDF_ESC:{value}") (at {x:g} {y:g} 0) (unit 1)',
                   '    (in_bom yes) (on_board yes)', f'    (uuid {uid})',
                   f'    (property "Reference" "{ref}" (at {x:g} {y-6:g} 0) (effects (font (size 1.27 1.27))))',
                   f'    (property "Value" "{display_value}" (at {x:g} {y+6:g} 0) (effects (font (size 1.27 1.27))))',
                   f'    (pin_names hide)', '    (exclude_from_sim no)',
                   f'    (instances (project "edf-esc" (path "/" (reference "{ref}") (unit 1))))', '  )']
    channel = {
        "A": ["+3V3", "SPI_SCK", "SPI_MISO", "NRST_A", "GND", "CURRENT_A", "VBUS_ADC_A", "BEMF_A_U", "BEMF_A_V", "BEMF_A_W", "NTC_A", "TIM1_BKIN_A", "PWM_A_UL", "PWM_A_VL", "PWM_A_WL", "GND", "GND", "PWM_A_UH", "PWM_A_VH", "PWM_A_WH", "GND", "GND", "SWDIO_A", "SWCLK_A", "GND", "GND", "THROTTLE_A", "GATE_SUPPLY_FAULT_A", "GND", "SPI_MOSI", "GND", "CS_A", "GND"],
        "B": ["+3V3", "SPI_SCK", "SPI_MISO", "NRST_B", "GND", "CURRENT_B", "VBUS_ADC_B", "BEMF_B_U", "BEMF_B_V", "BEMF_B_W", "NTC_B", "TIM1_BKIN_B", "PWM_B_UL", "PWM_B_VL", "PWM_B_WL", "GND", "GND", "PWM_B_UH", "PWM_B_VH", "PWM_B_WH", "GND", "GND", "SWDIO_B", "SWCLK_B", "GND", "GND", "THROTTLE_B", "GATE_SUPPLY_FAULT_B", "GND", "SPI_MOSI", "GND", "CS_B", "GND"],
    }
    # Labels are placed at the exact pin endpoints produced by build_symbol_library.
    label_id = 1
    for ref, value, x, y in instances:
        if ref.startswith("UCS"):
            ch = ref[-1]; nets_for_pins = ["+3V3", "+3V3", "GND", "GND", f"CURRENT_{ch}", "NC", f"KELVIN_{ch}+", f"KELVIN_{ch}-"]
        elif ref.startswith("UC"):
            nets_for_pins = channel[ref[-1]]
        elif ref.startswith("UG"):
            ch = ref[-1]; nets_for_pins = [f"PWM_{ch}_UL", f"PWM_{ch}_VL", f"PWM_{ch}_WL", "12V_GATE", "GND", "GND", "NC", "NC", f"G_{ch}_WL", f"G_{ch}_VL", f"G_{ch}_UL", f"MOTOR_{ch}_W", f"G_{ch}_WH", f"BST_{ch}_W", f"MOTOR_{ch}_V", f"G_{ch}_VH", f"BST_{ch}_V", f"MOTOR_{ch}_U", f"G_{ch}_UH", f"BST_{ch}_U", "NC", f"PWM_{ch}_UH", f"PWM_{ch}_VH", f"PWM_{ch}_WH", "GND"]
        elif ref.startswith("Q"):
            ch = ref[1]; group = (int(ref[2:]) - 1) // 3; phase = "UVW"[group // 2]; side = "HL"[group % 2]
            source = f"MOTOR_{ch}_{phase}" if side == "H" else f"BAT_{ch}-"; drain = f"BAT_{ch}+" if side == "H" else f"MOTOR_{ch}_{phase}"
            nets_for_pins = [source, source, source, f"G_{ch}_{phase}{side}_{(int(ref[2:])-1)%3+1}", drain, drain, drain, drain]
        elif ref.startswith("RG"):
            ch = ref[2]; idx = int(ref[3:]); group = (idx - 1) // 3; phase = "UVW"[group // 2]; side = "HL"[group % 2]; n = (idx - 1) % 3 + 1
            nets_for_pins = [f"G_{ch}_{phase}{side}", f"G_{ch}_{phase}{side}_{n}"]
        elif ref == "U12V":
            nets_for_pins = ["12V_SW", "12V_SW", "12V_FB", "GND", "NC", "BAT_A+", "BAT_A+", "NC"]
        elif ref == "UBEC":
            nets_for_pins = ["GND", "BEC_FB", "BEC_SW", "BAT_A+", "NC"]
        elif ref == "U3V3":
            nets_for_pins = ["GND", "+3V3", "5V_BEC"]
        else:
            continue
        count = len(nets_for_pins); height = max(5.08, count * 0.635); left_count = (count + 1) // 2
        for pin, net in enumerate(nets_for_pins, 1):
            row = pin - 1 if pin <= left_count else pin - left_count - 1
            px = x - 7.62 if pin <= left_count else x + 7.62
            py = y + height / 2 - 0.635 - row * 1.27
            px, py = round(px, 3), round(py, 3)
            lines += [f'  (label "{net}" (at {px:g} {py:g} 0) (fields_autoplaced)', '    (effects (font (size 1.27 1.27)))', f'    (uuid 5e5b24b0-462c-4f73-9fb1-{label_id:012d}))']
            lines += [f'  (wire (pts (xy {px:g} {py:g}) (xy {px:g} {py:g})) (stroke (width 0) (type default)) (uuid 7e5b24b0-462c-4f73-9fb1-{label_id:012d}))']
            label_id += 1
    lines += ['  (text "UNVALIDATED — REVIEW ONLY; DO NOT FABRICATE" (at 100 15 0)',
              '    (effects (font (size 2 2) (thickness 0.35)))',
              '    (uuid 6e5b24b0-462c-4f73-9fb1-000000000001))',
              '  (sheet_instances (path "/" (page "1")))', ')']
    return "\n".join(lines) + "\n"


def build_footprints() -> dict[str, str]:
    definitions: dict[str, str] = {}
    for package, value, count in (
        ("QFN24", "DRV8300DRGER", 25),
        ("QFN32", "PY32F030K28U6TR", 33),
        ("TSOT23-8", "INA190A3IDDFR", 8),
        ("SOIC8", "XL1509-ADJ", 8),
        ("TO220-5", "XL4016E1", 5),
        ("SOT23-3", "XC6206P332MR", 3),
    ):
        definitions[f"{package}.kicad_mod"] = _device("REF**", value, package, 0, 0, [None] * count, {})
    fet = _qfn_fet("REF**", 0, 0, "G", "S", "D", {"G": 1, "S": 2, "D": 3})
    definitions["PDFN56.kicad_mod"] = re.sub(r' \(net \d+ "[GSD]"\)', "", fet)
    resistor = _resistor("REF**", 0, 0, "1", "2", {"1": 1, "2": 2})
    definitions["R_0603.kicad_mod"] = re.sub(r' \(net \d+ "[12]"\)', "", resistor)
    return {name: content + ("\n" if not content.endswith("\n") else "") for name, content in definitions.items()}
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

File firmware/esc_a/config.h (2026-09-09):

#ifndef EDF_ESC_CHANNEL_CONFIG_H
#define EDF_ESC_CHANNEL_CONFIG_H
#define EDF_ESC_CHANNEL_ID 'A'
#define EDF_ESC_SPI_CS_PIN 24
#define EDF_ESC_DEFAULT_PWM_HZ 16000u
#define EDF_ESC_DEFAULT_POLE_COUNT 4u
#define EDF_ESC_HIGH_POWER_UNLOCKED 0
#endif

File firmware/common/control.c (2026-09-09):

#include "edf_esc/control.h"

#include <stddef.h>

static void trip(esc_state_t *state, uint32_t fault) {
    state->faults |= fault;
    state->commanded_duty = 0;
    state->mode = ESC_FAULT;
}

esc_config_t esc_default_config(void) {
    return (esc_config_t){
        .align_time_us = 200000,
        .ramp_time_us = 600000,
        .control_timeout_us = 100000,
        .software_target_ma = 100000,
        .soft_limit_ma = 120000,
        .aggressive_limit_ma = 130000,
        .hard_limit_ma = 150000,
        .temperature_warning_c = 85,
        .temperature_shutdown_c = 105,
        .undervoltage_mv = 14000,
        .overvoltage_mv = 27000,
        .stall_timeout_us = 100000,
    };
}

esc_outputs_t esc_outputs_for_sector(uint8_t sector) {
    static const esc_outputs_t table[6] = {
        {PHASE_PWM_HIGH, PHASE_LOW_ON, PHASE_FLOAT},
        {PHASE_PWM_HIGH, PHASE_FLOAT, PHASE_LOW_ON},
        {PHASE_FLOAT, PHASE_PWM_HIGH, PHASE_LOW_ON},
        {PHASE_LOW_ON, PHASE_PWM_HIGH, PHASE_FLOAT},
        {PHASE_LOW_ON, PHASE_FLOAT, PHASE_PWM_HIGH},
        {PHASE_FLOAT, PHASE_LOW_ON, PHASE_PWM_HIGH},
    };
    const esc_outputs_t all_off = {PHASE_FLOAT, PHASE_FLOAT, PHASE_FLOAT};
    return sector < 6 ? table[sector] : all_off;
}

void esc_init(esc_state_t *state, const esc_config_t *config) {
    (void)config;
    if (state == NULL) return;
    *state = (esc_state_t){.mode = ESC_DISARMED};
}

void esc_set_control(esc_state_t *state, uint16_t duty, uint32_t now_us) {
    if (state == NULL || state->mode == ESC_FAULT) return;
    state->commanded_duty = duty;
    state->last_control_us = now_us;
}

void esc_arm(esc_state_t *state, uint32_t now_us) {
    if (state == NULL || state->faults != 0 || state->mode == ESC_FAULT) return;
    state->mode = ESC_ALIGN;
    state->state_started_us = now_us;
    state->last_control_us = now_us;
    state->last_commutation_us = now_us;
}

void esc_step(esc_state_t *state, const esc_config_t *config, uint32_t now_us) {
    if (state == NULL || config == NULL || state->mode == ESC_DISARMED || state->mode == ESC_FAULT) return;
    if ((uint32_t)(now_us - state->last_control_us) > config->control_timeout_us) {
        trip(state, ESC_FAULT_CONTROL_TIMEOUT);
        return;
    }
    const uint32_t elapsed = now_us - state->state_started_us;
    if (state->mode == ESC_ALIGN && elapsed >= config->align_time_us) {
        state->mode = ESC_OPEN_LOOP_RAMP;
        state->state_started_us += config->align_time_us;
    }
    if (state->mode == ESC_OPEN_LOOP_RAMP && state->bemf_reliable &&
        (uint32_t)(now_us - state->state_started_us) >= config->ramp_time_us) {
        state->mode = ESC_CLOSED_LOOP;
        state->state_started_us = now_us;
    }
}

void esc_set_bemf_reliable(esc_state_t *state, bool reliable) {
    if (state != NULL) state->bemf_reliable = reliable;
}

uint16_t esc_limit_duty(const esc_config_t *config, uint32_t current_ma, uint16_t requested) {
    if (config == NULL || current_ma >= config->hard_limit_ma) return 0;
    if (current_ma <= config->soft_limit_ma) return requested;
    if (current_ma < config->aggressive_limit_ma) {
        const uint32_t span = config->aggressive_limit_ma - config->soft_limit_ma;
        const uint32_t excess = current_ma - config->soft_limit_ma;
        return (uint16_t)((uint32_t)requested * (2u * span - excess) / (2u * span));
    }
    const uint32_t span = config->hard_limit_ma - config->aggressive_limit_ma;
    const uint32_t remaining = config->hard_limit_ma - current_ma;
    return (uint16_t)((uint32_t)requested * remaining / (2u * span));
}

uint16_t esc_protected_duty(const esc_config_t *config, uint32_t current_ma,
                            int16_t temperature_c, uint16_t requested) {
    uint16_t limited = esc_limit_duty(config, current_ma, requested);
    if (config == NULL || temperature_c >= config->temperature_shutdown_c) return 0;
    if (temperature_c <= config->temperature_warning_c) return limited;
    const uint32_t span = (uint32_t)(config->temperature_shutdown_c - config->temperature_warning_c);
    const uint32_t remaining = (uint32_t)(config->temperature_shutdown_c - temperature_c);
    return (uint16_t)((uint32_t)limited * remaining / span);
}

void esc_evaluate_protection(esc_state_t *state, const esc_config_t *config,
                             uint32_t current_ma, int16_t temperature_c,
                             uint32_t bus_mv, uint32_t now_us) {
    if (state == NULL || config == NULL || state->mode == ESC_FAULT) return;
    if (current_ma >= config->hard_limit_ma) {
        trip(state, ESC_FAULT_OVERCURRENT);
    } else if (temperature_c >= config->temperature_shutdown_c) {
        trip(state, ESC_FAULT_OVERTEMPERATURE);
    } else if (bus_mv < config->undervoltage_mv) {
        trip(state, ESC_FAULT_UNDERVOLTAGE);
    } else if (bus_mv > config->overvoltage_mv) {
        trip(state, ESC_FAULT_OVERVOLTAGE);
    } else if (state->mode == ESC_CLOSED_LOOP &&
               (uint32_t)(now_us - state->last_commutation_us) > config->stall_timeout_us) {
        trip(state, ESC_FAULT_STALL);
    }
}

void esc_note_commutation(esc_state_t *state, uint32_t now_us) {
    if (state != NULL) state->last_commutation_us = now_us;
}

void esc_emergency_stop(esc_state_t *state) {
    if (state != NULL) trip(state, ESC_FAULT_EMERGENCY_STOP);
}

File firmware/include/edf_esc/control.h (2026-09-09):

#ifndef EDF_ESC_CONTROL_H
#define EDF_ESC_CONTROL_H

#include <stdbool.h>
#include <stdint.h>

typedef enum {
    PHASE_FLOAT = 0,
    PHASE_PWM_HIGH,
    PHASE_LOW_ON,
} phase_drive_t;

typedef struct {
    phase_drive_t u;
    phase_drive_t v;
    phase_drive_t w;
} esc_outputs_t;

typedef enum {
    ESC_DISARMED = 0,
    ESC_ALIGN,
    ESC_OPEN_LOOP_RAMP,
    ESC_CLOSED_LOOP,
    ESC_FAULT,
} esc_mode_t;

enum {
    ESC_FAULT_CONTROL_TIMEOUT = 1u << 0,
    ESC_FAULT_EMERGENCY_STOP = 1u << 1,
    ESC_FAULT_OVERCURRENT = 1u << 2,
    ESC_FAULT_GATE_SUPPLY = 1u << 3,
    ESC_FAULT_STARTUP = 1u << 4,
    ESC_FAULT_OVERTEMPERATURE = 1u << 5,
    ESC_FAULT_UNDERVOLTAGE = 1u << 6,
    ESC_FAULT_OVERVOLTAGE = 1u << 7,
    ESC_FAULT_STALL = 1u << 8,
};

typedef struct {
    uint32_t align_time_us;
    uint32_t ramp_time_us;
    uint32_t control_timeout_us;
    uint32_t software_target_ma;
    uint32_t soft_limit_ma;
    uint32_t aggressive_limit_ma;
    uint32_t hard_limit_ma;
    int16_t temperature_warning_c;
    int16_t temperature_shutdown_c;
    uint32_t undervoltage_mv;
    uint32_t overvoltage_mv;
    uint32_t stall_timeout_us;
} esc_config_t;

typedef struct {
    esc_mode_t mode;
    uint32_t faults;
    uint16_t commanded_duty;
    uint32_t last_control_us;
    uint32_t state_started_us;
    uint32_t last_commutation_us;
    bool bemf_reliable;
} esc_state_t;

esc_config_t esc_default_config(void);
esc_outputs_t esc_outputs_for_sector(uint8_t sector);
void esc_init(esc_state_t *state, const esc_config_t *config);
void esc_set_control(esc_state_t *state, uint16_t duty, uint32_t now_us);
void esc_arm(esc_state_t *state, uint32_t now_us);
void esc_step(esc_state_t *state, const esc_config_t *config, uint32_t now_us);
void esc_set_bemf_reliable(esc_state_t *state, bool reliable);
uint16_t esc_limit_duty(const esc_config_t *config, uint32_t current_ma, uint16_t requested);
uint16_t esc_protected_duty(const esc_config_t *config, uint32_t current_ma,
                            int16_t temperature_c, uint16_t requested);
void esc_evaluate_protection(esc_state_t *state, const esc_config_t *config,
                             uint32_t current_ma, int16_t temperature_c,
                             uint32_t bus_mv, uint32_t now_us);
void esc_note_commutation(esc_state_t *state, uint32_t now_us);
void esc_emergency_stop(esc_state_t *state);

#endif

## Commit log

2026-09-09 chore: initialize EDF-ESC public repository
2026-09-09 chore: publish EDF-ESC engineering baseline
    [alternates.csv, edf-esc.csv, edf-esc.kicad_pcb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]
2026-09-09 docs: add board completion execution plan
2026-09-09 feat: add connected dual ESC schematic
    [edf-esc.kicad_sch]
